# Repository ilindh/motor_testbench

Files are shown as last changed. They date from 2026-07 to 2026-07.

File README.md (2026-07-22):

<!-- KICAD_DIFF_GEN_START -->
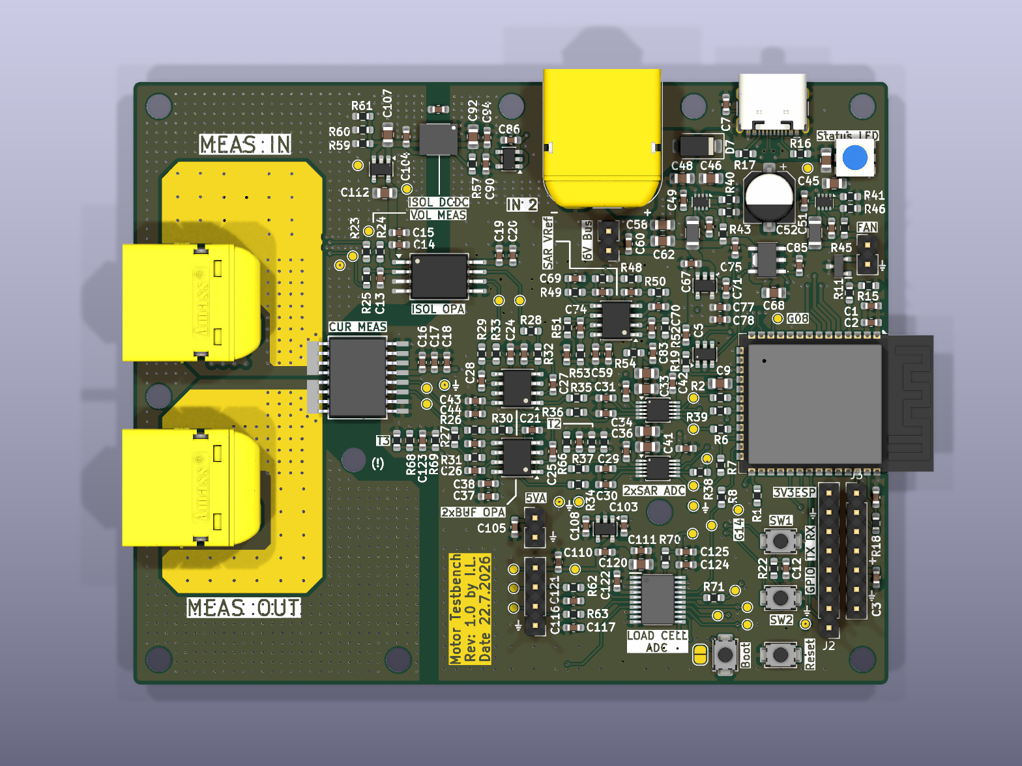
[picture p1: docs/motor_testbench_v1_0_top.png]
<p align="center"><br><b>Top</b></p>
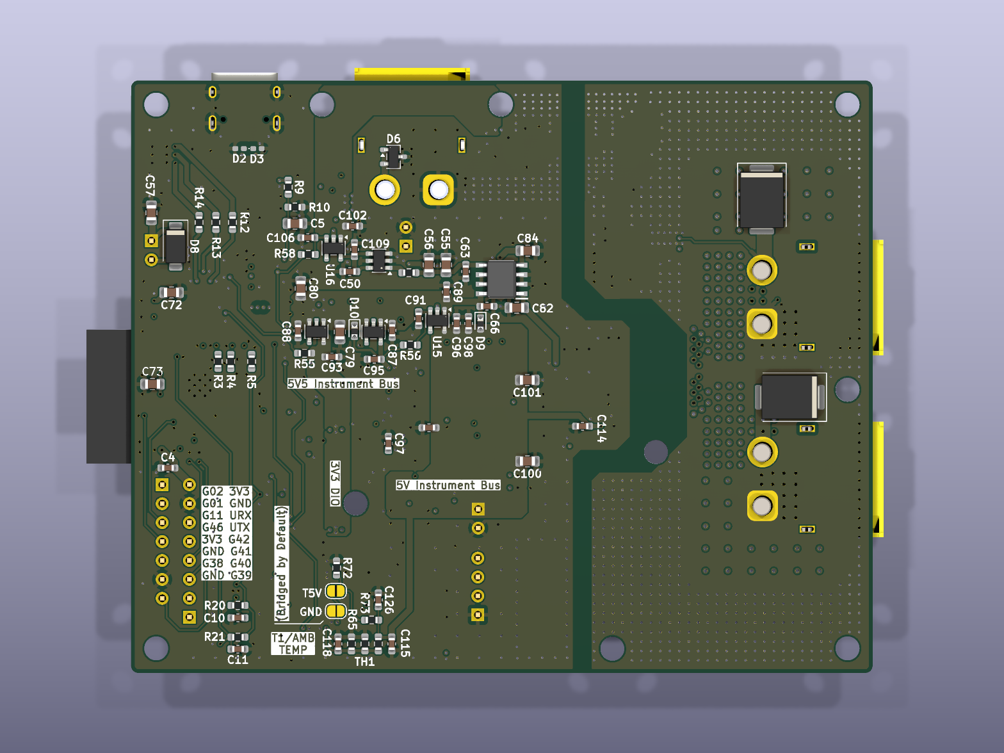
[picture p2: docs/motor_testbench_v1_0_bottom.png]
<p align="center"><br><b>Bottom</b></p>
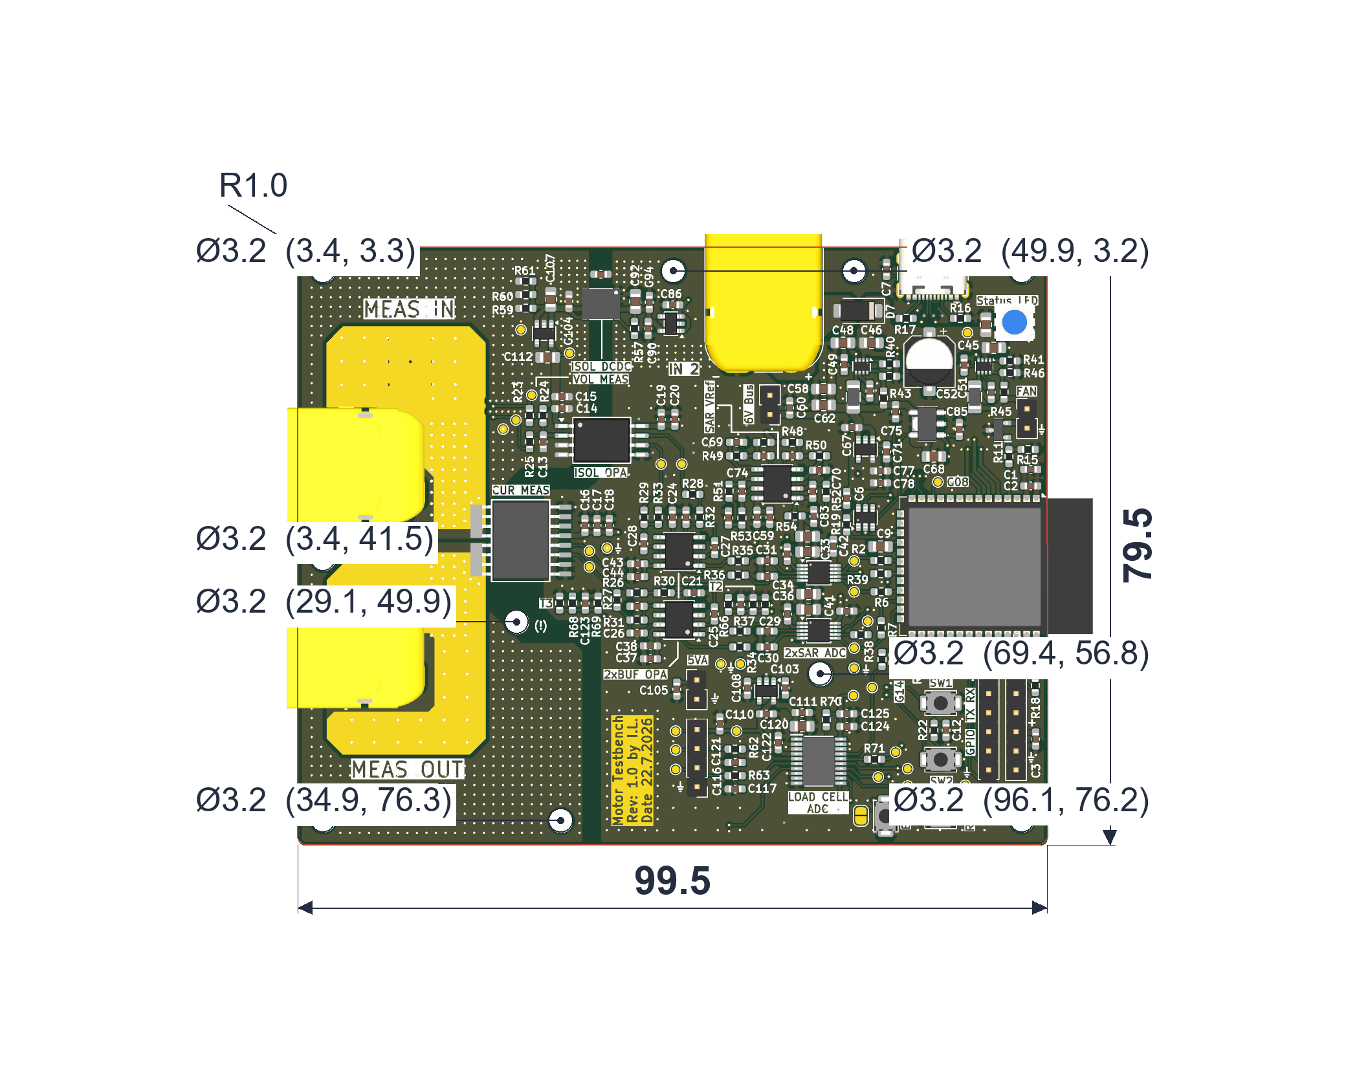
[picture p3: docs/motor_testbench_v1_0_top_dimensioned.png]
<p align="center"><br><b>Dimensions</b></p>

<p align="center"><br><b>Schematic — Page 1</b></p>
<p align="center"><br><b>Load Cell And Temperature Measurements — Page 2</b></p>
<p align="center"><br><b>Power Regulation — Page 3</b></p>
<p align="center"><br><b>Voltage And Current Measurements — Page 4</b></p>

---
## 🛠 Technical Hardware Summary
*Autogenerated by GitHub Command Center*

### 📋 Project Overview
| Metric | Value |
| :--- | :--- |
| **Board Dimensions** | 99.5 x 79.51 mm |
| **Total Area** | 7910.75 mm² |
| **Layer Count** | 6 Copper Layers |
| **Total Components** | 286 |
| **SMD Components** | 244 |
| **THT Components** | 9 |
| **Unique Parts** | 72 |
| **DRC Status** | ⚠️ 26 Errors, 106 Warnings |
| **KiCad Version** | 10.0.4 |

### 📐 Manufacturing & DRC
| Metric | Value |
| :--- | :--- |
| **Vias** | 1443 Total (1443 TH, 0 Blind, 0 Micro) |

### 📄 Architecture
- **Digital Buses:** `ESP_UART_RX, ESP_UART_TX, ESP_USB_D+, ESP_USB_D-`
- **Power Domains:** `+3V3, GND, GNDREF`

### ⚙️ Mechanical
- **Mounting Holes:** 10 (H10 (MountingHole_3.2mm_M3), H9 (MountingHole_3.2mm_M3), H7 (MountingHole_3.2mm_M3), H1 (MountingHole_3.2mm_M3), H8 (MountingHole_3.2mm_M3), H6 (MountingHole_3.2mm_M3), H2 (MountingHole_3.2mm_M3), H5 (MountingHole_3.2mm_M3), H4 (MountingHole_3.2mm_M3), H3 (MountingHole_3.2mm_M3))

### 🚫 Do Not Populate (DNP)
- C100 (22u)
- C101 (22u)
- C105 (1u)
- C126 (1u)
- C60 (1u)
- C8 (1u)
- C99 (100p)
- R18 (22R)
- R40 (R)
- R41 (R)
- R59 (220R)
- R60 (220R)
- R61 (220R)
- R72 (10k)
- R73 (10k)
- R8 (22R)

### 📝 Project TODOs
- TODO: Check Min / Max stable capacitances for the LDOS
- TODO: FIND PROPER 6V 800mA INPUT TO 3V3 LDO
- TODO: MAADOITA NÄMÄ?
- TODO: TARKASTA PINOUT: TLV9001SIDBVRG4\n
- TODO: VAIHDA TÄHÄN\nMouser No:\n637-PSOT36\nMfr. No:\nPSOT36
- TODO:\n\nVARMISTA ETTÄ PINNIT JA FOOTPRINT OIKEAT:\nPJA3402_R1_00001\nSOT-23-3\n

### 🧠 Core ICs & Modules
| Reference | Component | Function / Description |
| :--- | :--- | :--- |
| IC6 | [MCP3564RT-E_ST](https://componentsearchengine.com/search.html?searchString=MCP3564RT-E/ST) | Analog to Digital Converters - ADC 24-bit delta-sigma ADC w/Vref, Quad channel, 3V |
| IC1 | [PJA3402_R1_00001](https://componentsearchengine.com/search.html?searchString=PJA3402_R1_00001) | MOSFETs 30V N-Channel Enhancement Mode MOSFET |
| U1 | ESP32-S3-WROOM-1 | RF Module, ESP32-S3 SoC, Wi-Fi 802.11b/g/n, Bluetooth, BLE, 32-bit, 3.3V, onboard antenna, SMD |
| U2 | OPA310SxDBV | Single Rail-to-Rail Input/Output Operational Amplifier with Shutdown, 1.5..5.5V supply, 3MHz GBW, 250uV offset voltage, 150mA output current, SOT-23-6 |
| U8 | TPS62933 | 3.8-30V, 3A Synchronous Buck Converters with pulse frequency modulation (PFM), SOT583-8 |
| IC4 | [AP7361C-33Y5-13](https://componentsearchengine.com/search.html?searchString=AP7361C-33Y5-13) | DIODES INC. - AP7361C-33Y5-13 - LDO, FIXED, 3.3V, 1A, -40 TO 85DEG C |
| U10 | OPA2387DR | Precision, 10-MHz, Low-Noise, Low-Power, RRIO, CMOS Operational Amplifier, SOIC-8 |
| IC3 | [NCV8184DR2G](https://componentsearchengine.com/search.html?searchString=NCV8184DR2G) | 70 mA Source Capability; Output Tracks within +/- 3m V; Low Input Voltage Tracking Performance (Works Down to Vref = 2.0 V); Low Dropout (0.35 V Typ.@50 mA); Low Quiescent Current; Thermal Shutdown; AEC Qualified; PPAP Capable |
| U14 | TPS7A2018PDBVRG4 | LDO Voltage Regulators 300-mA ultra-low-noi se low-IQ low-dropo |
| U9 | TPS62933 | 3.8-30V, 3A Synchronous Buck Converters with pulse frequency modulation (PFM), SOT583-8 |
| U18 | TPS7A2045PDBVR | LDO Voltage Regulators 300-mA ultra-low-noi se low-IQ low-dropo |
| IC5 | [MIE1W0505BGLVH-3R-P](https://componentsearchengine.com/search.html?searchString=MIE1W0505BGLVH-3R-P) | Isolated DC/DC Converters - SMD Next gen ultra small size isolated power module |
| U7 | MCP1502T-50E/CHY | Voltage References 50 ppm 0.1% Voltage Reference |
| U11 | TPS7A2055PDBVR | LDO Voltage Regulators 300-mA ultra-low-noi se low-IQ low-dropo |
| U16 | TPS7A2055PDBVR | LDO Voltage Regulators 300-mA ultra-low-noi se low-IQ low-dropo |
| U15 | TPS7A2050PDBVR | LDO Voltage Regulators 300-mA ultra-low-noi se low-IQ low-dropo |
| U13 | TPS7A2033PDBVR | TPS7A2033PDBVR |
| U17 | TPS7A2033PDBVR | LDO Voltage Regulators 300-mA ultra-low-noi se low-IQ low-dropo |
| U12 | TPS7A2050PDBVR | LDO Voltage Regulators 300-mA ultra-low-noi se low-IQ low-dropo |
| U3 | [CZ3723](https://componentsearchengine.com/search.html?searchString=CZ3A05) | Board Mount Current Sensors 60A Precise unipolar Coreless Current Sensor w/UL61800 |
| U6 | OPA2328DR | Precision, 10-MHz, Low-Noise, Low-Power, RRIO, CMOS Operational Amplifier, SOIC-8 |
| U4 | AMC1351DWV | Precision Reinforced Isolated Amplifier, 5V Input, 300 kHz Bandwidth, 0.4V/V, 0.2% Gain Tolerance, Differential Output, SOIC-8 |
| U5 | OPA2328DR | Precision Amplifiers Dual-channel precis ion 50-uV offset vo |

### 🔌 Connectors & Interfaces
| Reference | Type | Component | Description |
| :--- | :--- | :--- | :--- |
| J11 | Connector | Conn_01x04_Pin | Generic connector, single row, 01x04, script generated |
| J3 | Connector | Conn_01x07_Pin | Generic connector, single row, 01x07, script generated |
| J1 | Connector | USB_C_Receptacle_USB2.0_16P | USB 2.0-only 16P Type-C Receptacle connector |
| J2 | Connector | Conn_01x08_Pin | Generic connector, single row, 01x08, script generated |
| J10 | Connector | Conn_01x02_Pin | Generic connector, single row, 01x02, script generated |
| J7 | Connector | Conn_01x02_Pin | Generic connector, single row, 01x02, script generated |
| J8 | Connector | Conn_01x02_Pin | Generic connector, single row, 01x02, script generated |
| J6 | Connector | V_bat_secondary | Generic connector, single row, 01x02, script generated |
| J5 | Connector | [XT60PW-M](https://componentsearchengine.com/search.html?searchString=XT60PW-M) | Connector: DC supply; socket; XT60; male; PIN: 2; on PCBs; THT; 30A |
| J4 | Connector | [XT60PW-M](https://componentsearchengine.com/search.html?searchString=XT60PW-M) | Connector: DC supply; socket; XT60; male; PIN: 2; on PCBs; THT; 30A |

### 📏 Passive Components
| Component | Breakdown |
| :--- | :--- |
| Capacitor | 97x0603, 28x0805 and 1xOther |
| Diode | 2x0402, 2x0603 and 6xOther |
| Inductor | 1x1206 |
| Resistor | 73x0603 |

---
<!-- KICAD_DIFF_GEN_END -->

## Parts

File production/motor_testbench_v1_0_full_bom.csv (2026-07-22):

Qty | Reference | Value | Footprint | Manufacturer_Part_Number | Description | DNP
63 | C1, C2, C3, C4, C6, C7, C14, C15, C16, C17, C18, C19, C20, C37, C38, C41, C42, C43, C44, C50, C59, C61, C63, C66, C67, C69, C70, C71, C77, C78, C81, C83, C85, C86, C87, C88, C89, C90, C91, C93, C94, C95, C96, C97, C98, C102, C103, C104, C106, C108, C109, C110, C111, C113, C114, C115, C118, C119, C121, C122, C123, C124, C125 | 1u | Capacitor_SMD:C_0603_1608Metric_Pad1.08x0.95mm_HandSolder |  | Unpolarized capacitor
16 | C5, C9, C45, C46, C47, C48, C55, C56, C68, C72, C73, C82, C84, C92, C112, C120 | 10u | Capacitor_SMD:C_0805_2012Metric_Pad1.18x1.45mm_HandSolder |  | Unpolarized capacitor
2 | C8, C126 | 1u | Capacitor_SMD:C_0603_1608Metric_Pad1.08x0.95mm_HandSolder |  | Unpolarized capacitor | DNP
2 | C10, C11 | 100n | Capacitor_SMD:C_0603_1608Metric_Pad1.08x0.95mm_HandSolder |  | BTN Debounce Cap
3 | C12, C53, C54 | 100n | Capacitor_SMD:C_0603_1608Metric_Pad1.08x0.95mm_HandSolder |  | Unpolarized capacitor
1 | C13 | 100p | Capacitor_SMD:C_0603_1608Metric_Pad1.08x0.95mm_HandSolder |  | USE 50V CAP HERE!, NP0 OR C0G SIGNAL CAP REQUIRED !
4 | C21, C22, C23, C24 | 100pF | Capacitor_SMD:C_0603_1608Metric_Pad1.08x0.95mm_HandSolder |  | SIGNAL CAP ! Use NP0 or similar.
4 | C25, C26, C27, C28 | 205pF | Capacitor_SMD:C_0603_1608Metric_Pad1.08x0.95mm_HandSolder |  | SIGNAL CAP ! Use NP0 or similar.
4 | C29, C30, C31, C32 | 1.7nF | Capacitor_SMD:C_0603_1608Metric_Pad1.08x0.95mm_HandSolder |  | SIGNAL CAP, USE NP0
4 | C33, C34, C35, C36 | 10u | Capacitor_SMD:C_0805_2012Metric_Pad1.18x1.45mm_HandSolder |  | SAR ADC Vref Capacitor (Very Cvritical!)
2 | C39, C40 | 1u | Capacitor_SMD:C_0603_1608Metric_Pad1.08x0.95mm_HandSolder |  | SAR ADC Ref Cap (critical)
2 | C49, C51 | 33n | Capacitor_SMD:C_0603_1608Metric_Pad1.08x0.95mm_HandSolder |  | Unpolarized capacitor
1 | C52 | 470u | Capacitor_SMD:CP_Elec_6.3x5.3 |  | Unpolarized capacitor
6 | C57, C58, C62, C79, C80, C107 | 22u | Capacitor_SMD:C_0805_2012Metric_Pad1.18x1.45mm_HandSolder |  | Unpolarized capacitor
2 | C64, C65 | 2.05u | Capacitor_SMD:C_0603_1608Metric_Pad1.08x0.95mm_HandSolder |  | Unpolarized capacitor
2 | C74, C76 | 4.7nF | Capacitor_SMD:C_0603_1608Metric_Pad1.08x0.95mm_HandSolder |  | Unpolarized capacitor
1 | C75 | 10u | Capacitor_SMD:C_0603_1608Metric_Pad1.08x0.95mm_HandSolder |  | Unpolarized capacitor
2 | C116, C117 | 100n | Capacitor_SMD:C_0603_1608Metric_Pad1.08x0.95mm_HandSolder |  | Load Cell Input Filter Capacitor, USE NP0
18 | CS1, CS2, DIO1, Dout1, GND1, GND2, GND3, GND4, GND5, I1, I2, I3, I4, IN1, SCLK1, Vref1, Vsig1, Vsig2 | TestPoint | TestPoint:TestPoint_Pad_D1.0mm |  | test point
1 | D1 | LED_RGB | LED_SMD:LED_RGB_PLCC-6 |  | RGB LED, 6 pin package
2 | D2, D3 | GG040205170N2P | Diode_SMD:D_0402_1005Metric_Pad0.77x0.64mm_HandSolder |  | Diode
2 | D4, D5 | 1.5SMCxxCA | Diode_SMD:D_SMC |  | 1500W bidirectional TVS diode, SMC (DO-201AB)
1 | D6 | ESDA5V3L | Package_TO_SOT_SMD:SOT-23-3 |  | TVS Diode Array, 5.5V Standoff, 2 Channels, SOT23
2 | D7, D8 | SB56AFC-AU_R1_000A1 | Diode_SMD:D_SMA |  | Schottky Diodes & Rectifiers 60V,Schottky,SMAF-C,5A
2 | D9, D10 | CDBU40-HF | Diode_SMD:D_0603_1608Metric |  | 40V 200mA Schottky Barrier Rectifier Diode, 0603
1 | IC1 | PJA3402_R1_00001 | SamacSys_Parts:SOT95P240X110-3N | PJA3402_R1_00001 | MOSFETs 30V N-Channel Enhancement Mode MOSFET
1 | IC3 | NCV8184DR2G | SamacSys_Parts:SOIC127P600X175-8N | NCV8184DR2G | 70 mA Source Capability; Output Tracks within +/- 3m V; Low Input Voltage Tracking Performance (Works Down to Vref = 2.0 V); Low Dropout (0.35 V Typ.@50 mA); Low Quiescent Current; Thermal Shutdown; AEC Qualified; PPAP Capable
1 | IC4 | AP7361C-33Y5-13 | SamacSys_Parts:AP7361CY513 | AP7361C-33Y5-13 | DIODES INC. - AP7361C-33Y5-13 - LDO, FIXED, 3.3V, 1A, -40 TO 85DEG C
1 | IC5 | MIE1W0505BGLVH-3R-P | SamacSys_Parts:MIE1W0505BGLVH3RP | MIE1W0505BGLVH-3R-P | Isolated DC/DC Converters - SMD Next gen ultra small size isolated power module
1 | IC6 | MCP3564RT-E_ST | SamacSys_Parts:SOP65P640X120-20N | MCP3564RT-E/ST | Analog to Digital Converters - ADC 24-bit delta-sigma ADC w/Vref, Quad channel, 3V
1 | J1 | USB_C_Receptacle_USB2.0_16P | Connector_USB:USB_C_Receptacle_HCTL_HC-TYPE-C-16P-01A |  | USB 2.0-only 16P Type-C Receptacle connector
1 | J2 | Conn_01x08_Pin | Connector_PinHeader_2.54mm:PinHeader_1x08_P2.54mm_Vertical |  | Generic connector, single row, 01x08, script generated
1 | J3 | Conn_01x07_Pin | Connector_PinHeader_2.54mm:PinHeader_1x07_P2.54mm_Vertical |  | Generic connector, single row, 01x07, script generated
2 | J4, J5 | XT60PW-M | Connector_AMASS:AMASS_XT60PW-M_1x02_P7.20mm_Horizontal | XT60PW-M | Connector: DC supply; socket; XT60; male; PIN: 2; on PCBs; THT; 30A
1 | J6 | V_bat_secondary | custom_footprints:AMASS_XT60PW-M_1x02_P7.20mm_Horizontal_with3DModel |  | Generic connector, single row, 01x02, script generated
3 | J7, J8, J10 | Conn_01x02_Pin | Connector_PinHeader_2.54mm:PinHeader_1x02_P2.54mm_Vertical |  | Generic connector, single row, 01x02, script generated
1 | J11 | Conn_01x04_Pin | Connector_PinHeader_2.54mm:PinHeader_1x04_P2.54mm_Vertical |  | Generic connector, single row, 01x04, script generated
1 | JP1 | Jumper_2_Open | Jumper:SolderJumper-2_P1.3mm_Open_RoundedPad1.0x1.5mm |  | Jumper, 2-pole, open
1 | L1 | 12u | Inductor_SMD:L_1206_3216Metric_Pad1.42x1.75mm_HandSolder |  | Inductor
1 | Lw1 | 6.8u | Inductor_SMD:L_1206_3216Metric_Pad1.42x1.75mm_HandSolder |  | Inductor
2 | MCP1, MCP2 | MCP33131D-10-E/MS | Package_SO:MSOP-10_3x3mm_P0.5mm |  | 16-bit ADC
1 | MCP33131 |  | Package_SO:MSOP-10_3x3mm_P0.5mm |  | 16-bit ADC
5 | R1, R10, R20, R21, R22 | 10k | Resistor_SMD:R_0603_1608Metric_Pad0.98x0.95mm_HandSolder |  | Voltage Meas Resistor 2
6 | R2, R6, R7, R19, R38, R39 | 22R | Resistor_SMD:R_0603_1608Metric_Pad0.98x0.95mm_HandSolder |  | Resistor
6 | R3, R4, R5, R62, R63, R71 | 22R | Resistor_SMD:R_0603_1608Metric_Pad0.98x0.95mm_HandSolder |  | Load Cell Inpu Filter Resistor
1 | R8 | 22R | Resistor_SMD:R_0603_1608Metric_Pad0.98x0.95mm_HandSolder |  | Load Cell Inpu Filter Resistor | DNP
1 | R9 | 100k | Resistor_SMD:R_0603_1608Metric_Pad0.98x0.95mm_HandSolder |  | Voltage Meas Resistor 1
1 | R11 | 220 | Resistor_SMD:R_0603_1608Metric_Pad0.98x0.95mm_HandSolder |  | Resistor
3 | R12, R13, R14 | 330R | Resistor_SMD:R_0603_1608Metric_Pad0.98x0.95mm_HandSolder
13 | R15, R44, R46, R49, R50, R51, R52, R55, R56, R58, R64, R66, R68 | 10k | Resistor_SMD:R_0603_1608Metric_Pad0.98x0.95mm_HandSolder |  | Resistor
2 | R16, R17 | 5.1k | Resistor_SMD:R_0603_1608Metric_Pad0.98x0.95mm_HandSolder |  | Resistor
1 | R18 | 22R | Resistor_SMD:R_0603_1608Metric_Pad0.98x0.95mm_HandSolder |  | Resistor | DNP
1 | R23 | 18k | Resistor_SMD:R_0603_1608Metric_Pad0.98x0.95mm_HandSolder |  | Voltage Meas Resistor 1
1 | R24 | 18k | Resistor_SMD:R_0603_1608Metric_Pad0.98x0.95mm_HandSolder |  | Voltage Meas Resistor 2
1 | R25 | 6.2k | Resistor_SMD:R_0603_1608Metric_Pad0.98x0.95mm_HandSolder |  | Voltage Meas Resistor 3 (RSENS)
4 | R26, R27, R28, R29 | 2.37k | Resistor_SMD:R_0603_1608Metric_Pad0.98x0.95mm_HandSolder |  | Sensitive Filter Resistor!
4 | R30, R31, R32, R33 | 3.32k | Resistor_SMD:R_0603_1608Metric_Pad0.98x0.95mm_HandSolder |  | Sensitive Filter Resistor!
4 | R34, R35, R36, R37 | 22R | Resistor_SMD:R_0603_1608Metric_Pad0.98x0.95mm_HandSolder |  | Sensitive Filter Resistor!
1 | R42 | 5R | Resistor_SMD:R_0603_1608Metric_Pad0.98x0.95mm_HandSolder |  | Resistor
1 | R43 | 63k | Resistor_SMD:R_0603_1608Metric_Pad0.98x0.95mm_HandSolder |  | Resistor
1 | R45 | 140k | Resistor_SMD:R_0603_1608Metric_Pad0.98x0.95mm_HandSolder |  | Resistor
2 | R47, R48 | 8.2k | Resistor_SMD:R_0603_1608Metric_Pad0.98x0.95mm_HandSolder |  | Resistor
2 | R53, R54 | 2R | Resistor_SMD:R_0603_1608Metric_Pad0.98x0.95mm_HandSolder |  | Resistor
1 | R57 | 100k | Resistor_SMD:R_0603_1608Metric_Pad0.98x0.95mm_HandSolder |  | Dummy Load Resistor for ISODCDC Converter, P = 0.25W
3 | R65, R67, R69 | 18k | Resistor_SMD:R_0603_1608Metric_Pad0.98x0.95mm_HandSolder |  | Resistor
1 | R70 | 100k | Resistor_SMD:R_0603_1608Metric_Pad0.98x0.95mm_HandSolder |  | Load Cell Inpu Filter Resistor
2 | R72, R73 | 10k | Resistor_SMD:R_0603_1608Metric_Pad0.98x0.95mm_HandSolder |  | NTC 5V Ref voltage divider resistors | DNP
4 | SWd1, SWd2, SWd3, SWd4 | SW_Push | Button_Switch_SMD:SW_SPST_TS-1088-xR020 |  | Push button switch, generic, two pins
3 | TH1, TH2, TH3 | NTCG164BH103JT1 | Resistor_SMD:R_0603_1608Metric_Pad0.98x0.95mm_HandSolder |  | Temperature dependent resistor, negative temperature coefficient
1 | U1 | ESP32-S3-WROOM-1 | RF_Module:ESP32-S3-WROOM-1 |  | RF Module, ESP32-S3 SoC, Wi-Fi 802.11b/g/n, Bluetooth, BLE, 32-bit, 3.3V, onboard antenna, SMD
1 | U2 | OPA310SxDBV | Package_TO_SOT_SMD:SOT-23-6 |  | Single Rail-to-Rail Input/Output Operational Amplifier with Shutdown, 1.5..5.5V supply, 3MHz GBW, 250uV offset voltage, 150mA output current, SOT-23-6
1 | U3 | CZ3723 | custom_footprints:CZ3723 | CZ3A05 | Board Mount Current Sensors 60A Precise unipolar Coreless Current Sensor w/UL61800
1 | U4 | AMC1351DWV | Package_SO:SOIC-8_7.5x5.85mm_P1.27mm |  | Precision Reinforced Isolated Amplifier, 5V Input, 300 kHz Bandwidth, 0.4V/V, 0.2% Gain Tolerance, Differential Output, SOIC-8
1 | U5 | OPA2328DR | Package_SO:SOIC-8_3.9x4.9mm_P1.27mm |  | Precision Amplifiers Dual-channel precis ion 50-uV offset vo
1 | U6 | OPA2328DR | Package_SO:SOIC-8_3.9x4.9mm_P1.27mm |  | Precision, 10-MHz, Low-Noise, Low-Power, RRIO, CMOS Operational Amplifier, SOIC-8
1 | U7 | MCP1502T-50E/CHY | Package_TO_SOT_SMD:SOT-23-6 |  | Voltage References 50 ppm 0.1% Voltage Reference
2 | U8, U9 | TPS62933 | Package_TO_SOT_SMD:SOT-583-8 |  | 3.8-30V, 3A Synchronous Buck Converters with pulse frequency modulation (PFM), SOT583-8
1 | U10 | OPA2387DR | Package_SO:SOIC-8_3.9x4.9mm_P1.27mm |  | Precision, 10-MHz, Low-Noise, Low-Power, RRIO, CMOS Operational Amplifier, SOIC-8
2 | U11, U16 | TPS7A2055PDBVR | Package_TO_SOT_SMD:SOT-23-5 |  | LDO Voltage Regulators 300-mA ultra-low-noi se low-IQ low-dropo
2 | U12, U15 | TPS7A2050PDBVR | Package_TO_SOT_SMD:SOT-23-5 |  | LDO Voltage Regulators 300-mA ultra-low-noi se low-IQ low-dropo
1 | U13 | TPS7A2033PDBVR | Package_TO_SOT_SMD:SOT-23-5 |  | TPS7A2033PDBVR
1 | U14 | TPS7A2018PDBVRG4 | Package_TO_SOT_SMD:SOT-23-5 |  | LDO Voltage Regulators 300-mA ultra-low-noi se low-IQ low-dropo
1 | U17 | TPS7A2033PDBVR | Package_TO_SOT_SMD:SOT-23-5 |  | LDO Voltage Regulators 300-mA ultra-low-noi se low-IQ low-dropo
1 | U18 | TPS7A2045PDBVR | Package_TO_SOT_SMD:SOT-23-5 |  | LDO Voltage Regulators 300-mA ultra-low-noi se low-IQ low-dropo

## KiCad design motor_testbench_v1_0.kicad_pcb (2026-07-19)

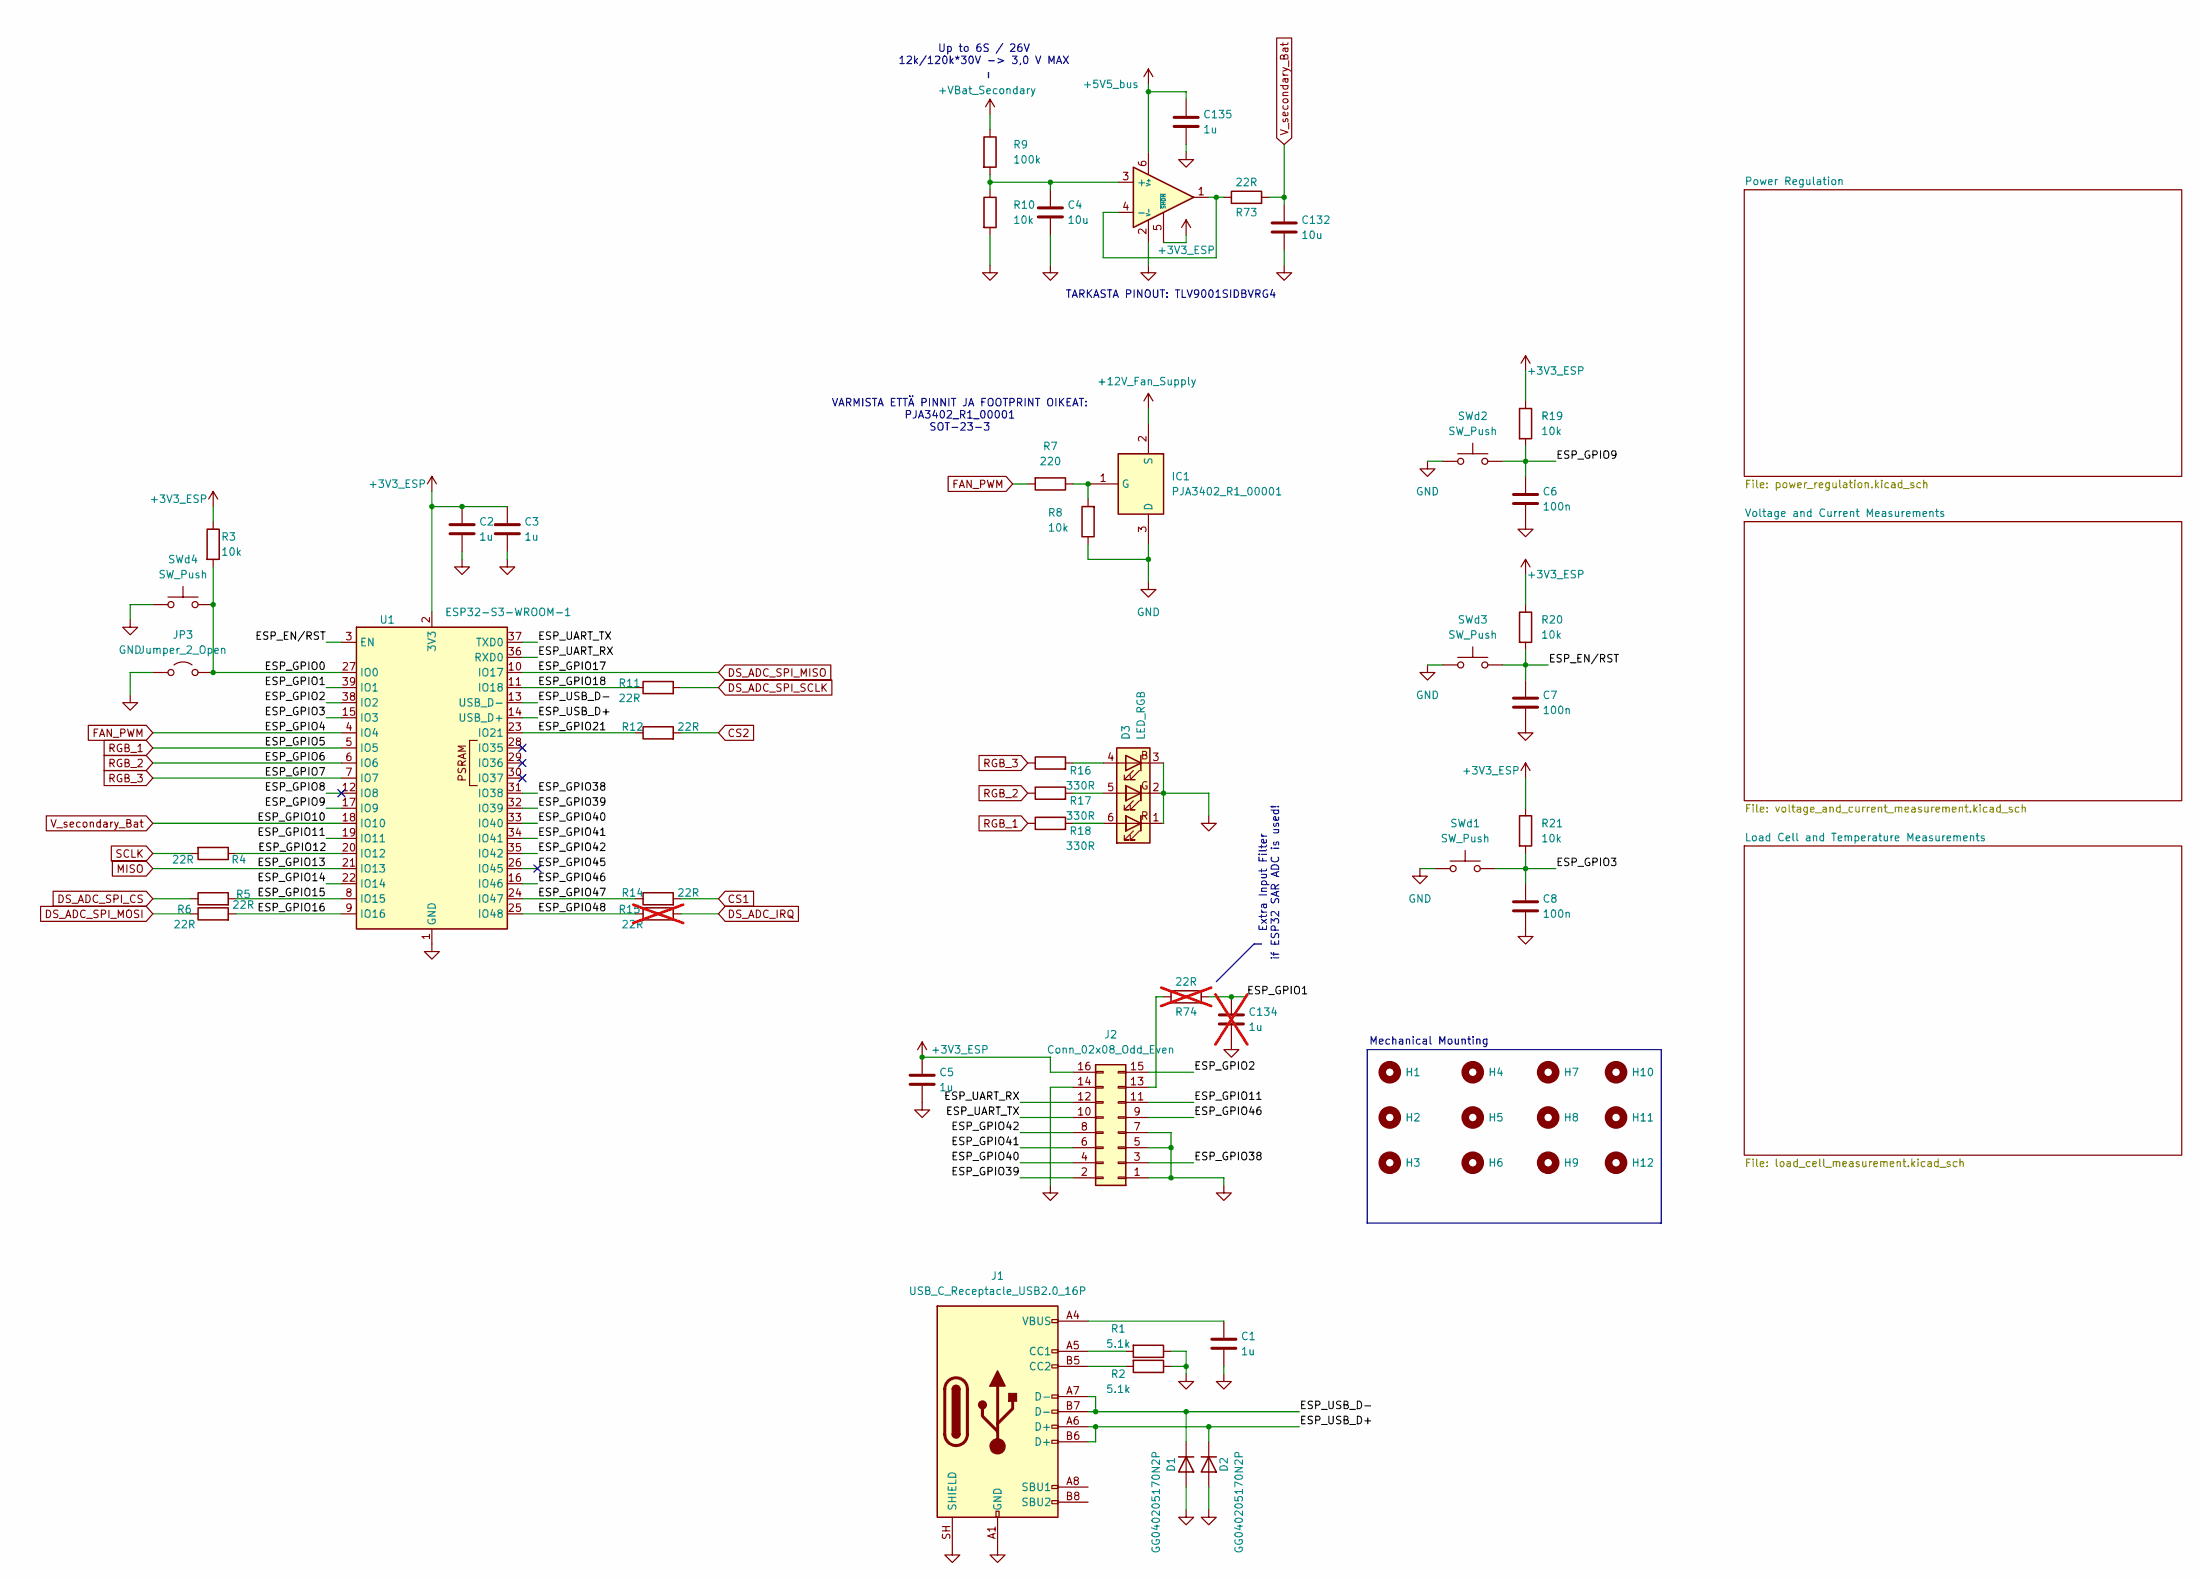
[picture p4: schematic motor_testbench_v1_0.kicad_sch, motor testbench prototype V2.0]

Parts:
C1, C2, C3, C5, C135: 1u; C_0603_1608Metric_Pad1.08x0.95mm_HandSolder
C4, C132: 10u; C_0603_1608Metric_Pad1.08x0.95mm_HandSolder
C6, C7, C8: 100n; C_0603_1608Metric_Pad1.08x0.95mm_HandSolder
C134: 1u; C_0603_1608Metric_Pad1.08x0.95mm_HandSolder; not fitted
D1, D2: GG040205170N2P; D_0402_1005Metric_Pad0.77x0.64mm_HandSolder
D3: LED_RGB; LED_RGB_PLCC-6
H1, H2, H3, H4, H5, H6, H7, H8, H9, H10, H11, H12: MountingHole; MountingHole_2.2mm_M2_DIN965
IC1: PJA3402_R1_00001; SOT95P240X110-3N; Manufacturer_Part_Number PJA3402_R1_00001
J1: USB_C_Receptacle_USB2.0_16P; USB_C_Receptacle_HCTL_HC-TYPE-C-16P-01A
J2: Conn_02x08_Odd_Even; PinHeader_2x08_P2.54mm_Vertical
JP3: Jumper_2_Open; SolderJumper-2_P1.3mm_Open_RoundedPad1.0x1.5mm
R1, R2: 5.1k; R_0603_1608Metric_Pad0.98x0.95mm_HandSolder
R3, R8, R10, R19, R20, R21: 10k; R_0603_1608Metric_Pad0.98x0.95mm_HandSolder
R4, R5, R6, R11, R12, R14, R73: 22R; R_0603_1608Metric_Pad0.98x0.95mm_HandSolder
R7: 220; R_0603_1608Metric_Pad0.98x0.95mm_HandSolder
R9: 100k; R_0603_1608Metric_Pad0.98x0.95mm_HandSolder
R15, R74: 22R; R_0603_1608Metric_Pad0.98x0.95mm_HandSolder; not fitted
R16, R17, R18: 330R; R_0603_1608Metric_Pad0.98x0.95mm_HandSolder
SWd1, SWd2, SWd3, SWd4: SW_Push; SW_SPST_TS-1088-xR020
U1: ESP32-S3-WROOM-1
U21: OPA310SxDBV; SOT-23-6

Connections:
+3V3_ESP: C2.1, C3.1, C5.1, J2.16, R3.1, R19.1, R20.1, R21.1, U1.2 (3V3), U21.5 (~SHDN); also elsewhere on the board
+5V5_bus: C135.1, U21.6 (V+); also elsewhere on the board
+12V_Fan_Supply: IC1.2 (S); also elsewhere on the board
+VBat_Secondary: R9.1; also elsewhere on the board
/ESP_EN/RST: C7.1, R20.2, SWd3.2, U1.3 (EN)
/ESP_GPIO0: JP3.2 (B), R3.2, SWd4.2, U1.27 (IO0)
/ESP_GPIO1: C134.1, R74.2, U1.39 (IO1)
/ESP_GPIO2: J2.15, U1.38 (IO2)
/ESP_GPIO3: C8.1, R21.2, SWd1.2, U1.15 (IO3)
/ESP_GPIO8: U1.12 (IO8)
/ESP_GPIO9: C6.1, R19.2, SWd2.2, U1.17 (IO9)
/ESP_GPIO11: J2.11, U1.19 (IO11)
/ESP_GPIO12: R4.1, U1.20 (IO12)
/ESP_GPIO14: U1.22 (IO14)
/ESP_GPIO15: R5.2, U1.8 (IO15)
/ESP_GPIO16: R6.2, U1.9 (IO16)
/ESP_GPIO18: R11.1, U1.11 (IO18)
/ESP_GPIO21: R12.1, U1.23 (IO21)
/ESP_GPIO38: J2.3, U1.31 (IO38)
/ESP_GPIO39: J2.2, U1.32 (IO39)
/ESP_GPIO40: J2.4, U1.33 (IO40)
/ESP_GPIO41: J2.6, U1.34 (IO41)
/ESP_GPIO42: J2.8, U1.35 (IO42)
/ESP_GPIO45: U1.26 (IO45)
/ESP_GPIO46: J2.9, U1.16 (IO46)
/ESP_GPIO47: R14.1, U1.24 (IO47)
/ESP_GPIO48: R15.1, U1.25 (IO48)
/ESP_UART_RX: J2.12, U1.36 (RXD0)
/ESP_UART_TX: J2.10, U1.37 (TXD0)
/ESP_USB_D+: D2.1 (K), J1.A6 (D+), J1.B6 (D+), U1.14 (USB_D+)
/ESP_USB_D-: D1.1 (K), J1.A7 (D-), J1.B7 (D-), U1.13 (USB_D-)
CS1: R14.2; also elsewhere on the board
CS2: R12.2; also elsewhere on the board
DS_ADC_IRQ: R15.2; also elsewhere on the board
DS_ADC_SPI_CS: R5.1; also elsewhere on the board
DS_ADC_SPI_MISO: U1.10 (IO17); also elsewhere on the board
DS_ADC_SPI_MOSI: R6.1; also elsewhere on the board
DS_ADC_SPI_SCLK: R11.2; also elsewhere on the board
FAN_PWM: R7.2, U1.4 (IO4)
GND: C1.2, C2.2, C3.2, C4.2, C5.2, C6.2, C7.2, C8.2, C132.2, C134.2, C135.2, D1.2 (A), D2.2 (A), D3.1 (RK), D3.2 (GK), D3.3 (BK), IC1.3 (D), J1.A1 (GND), J1.A12 (GND), J1.B1 (GND), J1.B12 (GND), J1.SH (SHIELD), J2.1, J2.5, J2.7, J2.14, JP3.1 (A), R1.1, R2.1, R8.1, R10.2, SWd1.1, SWd2.1, SWd3.1, SWd4.1, U1.1 (GND), U1.40 (GND), U1.41 (GND), U21.2 (V-); also elsewhere on the board
MISO: U1.21 (IO13); also elsewhere on the board
unnamed: C1.1, J1.A4 (VBUS), J1.A9 (VBUS), J1.B4 (VBUS), J1.B9 (VBUS)
unnamed: D3.4 (BA), R16.2
unnamed: D3.5 (GA), R17.2
unnamed: D3.6 (RA), R18.2
unnamed: IC1.1 (G), R7.1, R8.2
unnamed: J1.A5 (CC1), R1.2
unnamed: J1.B5 (CC2), R2.2
unnamed: J2.13, R74.1
unnamed: C4.1, R9.2, R10.1, U21.3 (+)
unnamed: R73.1, U21.1, U21.4 (-)
RGB_1: R18.1, U1.5 (IO5)
RGB_2: R17.1, U1.6 (IO6)
RGB_3: R16.1, U1.7 (IO7)
SCLK: R4.2; also elsewhere on the board
V_secondary_Bat: C132.1, R73.2, U1.18 (IO10)

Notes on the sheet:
Extra Input Filter if ESP32 SAR ADC is used!
Mechanical Mounting
TARKASTA PINOUT: TLV9001SIDBVRG4
VARMISTA ETTÄ PINNIT JA FOOTPRINT OIKEAT: PJA3402_R1_00001 SOT-23-3
Up to 6S / 26V 12k/120k*30V -> 3,0 V MAX

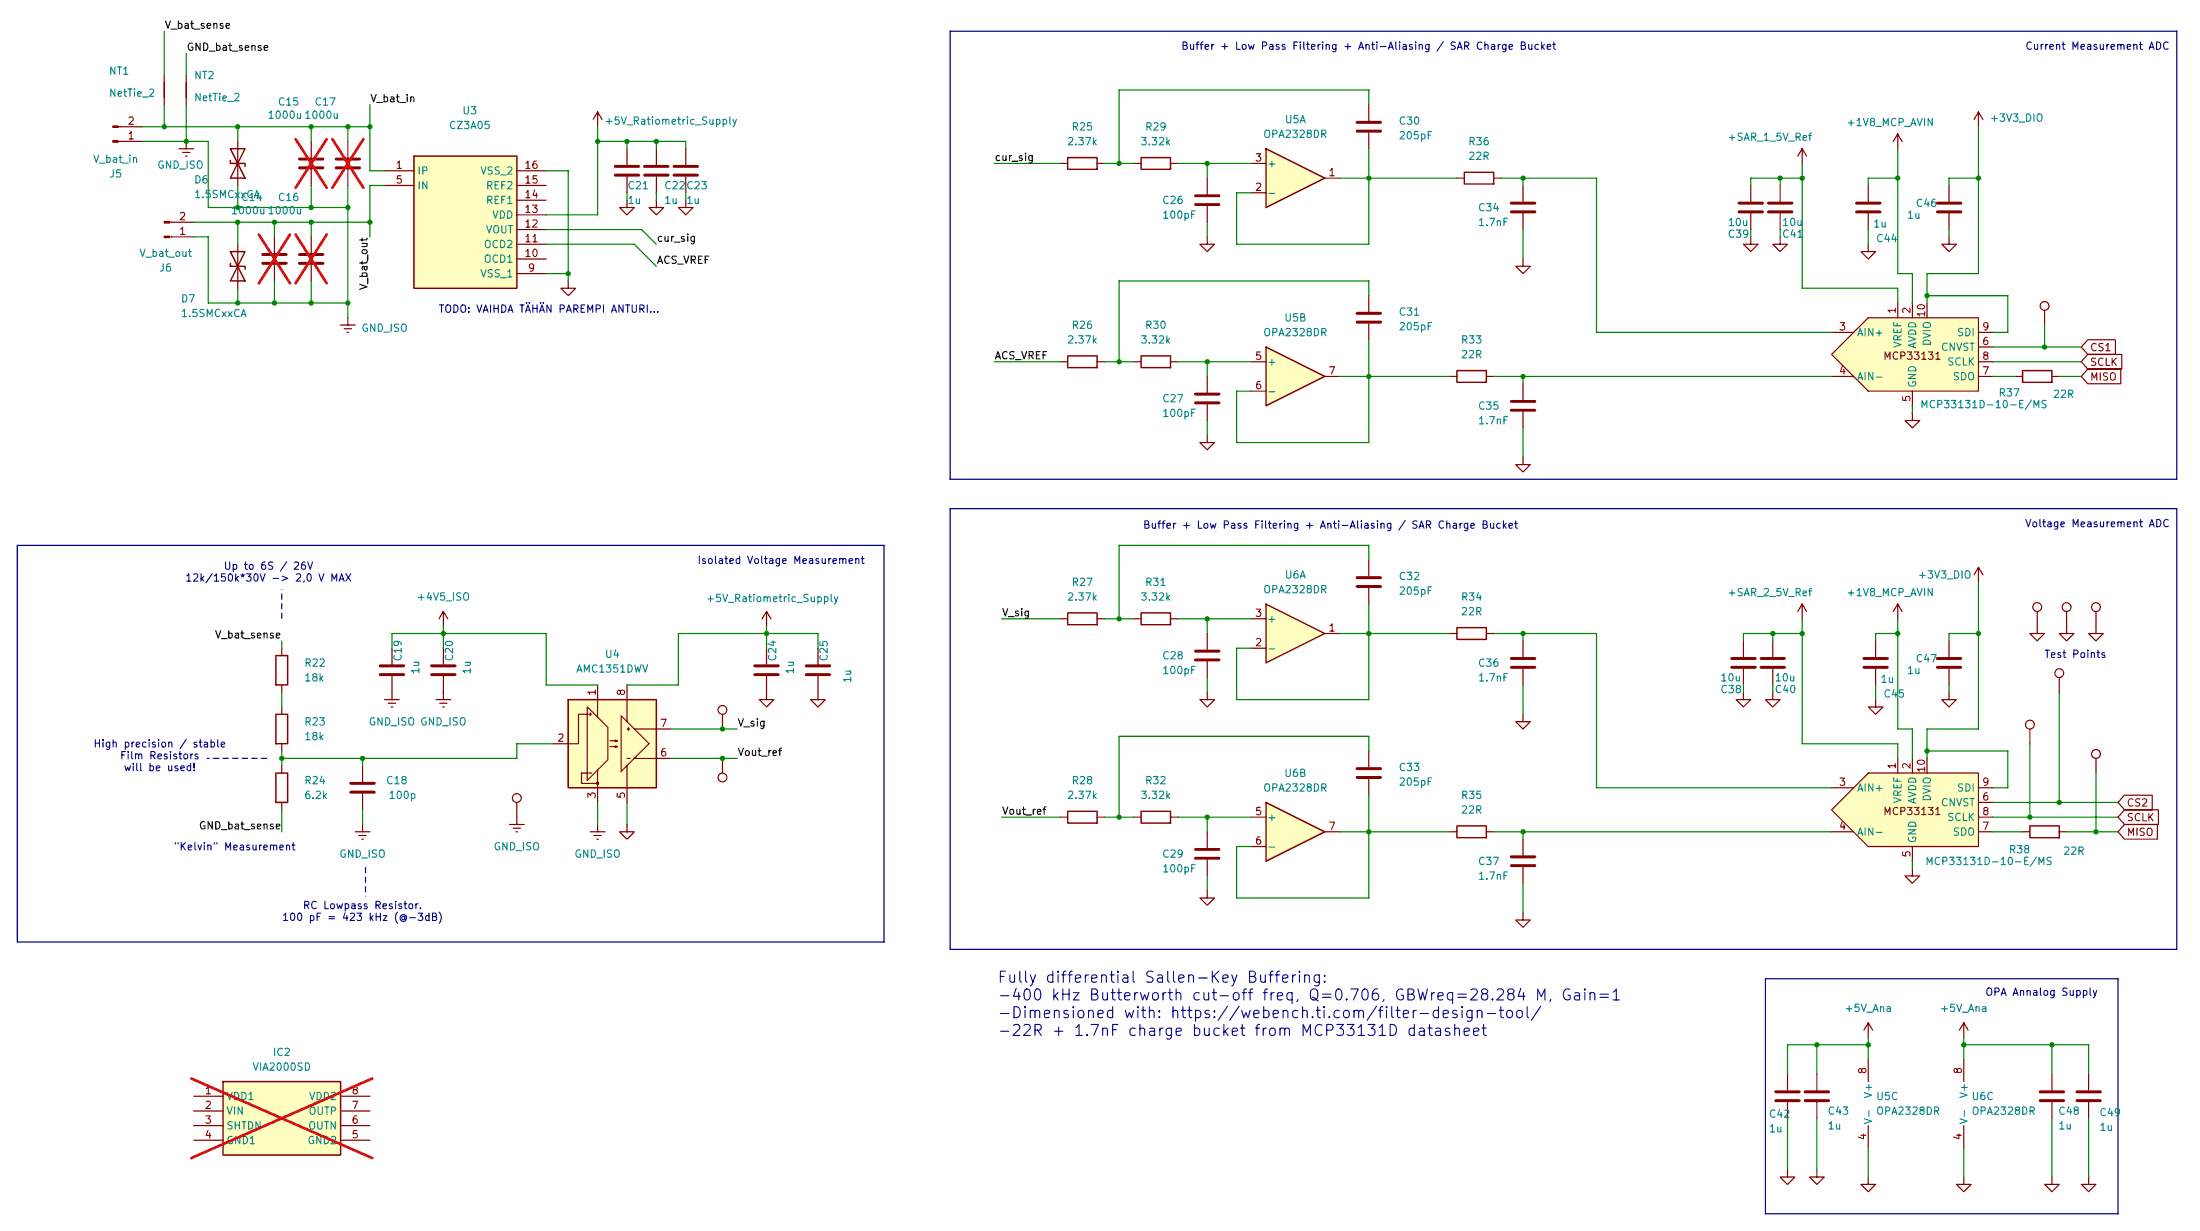
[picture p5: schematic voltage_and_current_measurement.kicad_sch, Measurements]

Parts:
C14, C15, C16, C17: 1000u; C_Radial_D8.0mm_H11.5mm_P3.50mm; not fitted
C18: 100p; C_0603_1608Metric_Pad1.08x0.95mm_HandSolder
C19, C20, C21, C22, C23, C24, C25, C42, C43, C44, C45, C46, C47, C48, C49: 1u; C_0603_1608Metric_Pad1.08x0.95mm_HandSolder
C26, C27, C28, C29: 100pF; C_0603_1608Metric_Pad1.08x0.95mm_HandSolder
C30, C31, C32, C33: 205pF; C_0603_1608Metric_Pad1.08x0.95mm_HandSolder
C34, C35, C36, C37: 1.7nF; C_0603_1608Metric_Pad1.08x0.95mm_HandSolder
C38, C39, C40, C41: 10u; C_0603_1608Metric_Pad1.08x0.95mm_HandSolder
CS1, CS2: TestPoint; TestPoint_Pad_D1.0mm
D6, D7: 1.5SMCxxCA; D_SMC
Dout1: TestPoint; TestPoint_Pad_D1.0mm
GND1, GND2, GND3, GND4: TestPoint; TestPoint_Pad_D1.0mm
IC2: VIA2000SD; SOIC127P1150X280-8N; Manufacturer_Part_Number VIA2000SD; not fitted
J5: V_bat_in; AMASS_XT60PW-M_1x02_P7.20mm_Horizontal_with3DModel
J6: V_bat_out; AMASS_XT60PW-M_1x02_P7.20mm_Horizontal_with3DModel
MCP1, MCP2: MCP33131D-10-E/MS; MSOP-10_3x3mm_P0.5mm
NT1, NT2: NetTie_2; NetTie-2_SMD_Pad0.5mm
R22, R23: 18k; R_0603_1608Metric_Pad0.98x0.95mm_HandSolder
R24: 6.2k; R_0603_1608Metric_Pad0.98x0.95mm_HandSolder
R25, R26, R27, R28: 2.37k; R_0603_1608Metric_Pad0.98x0.95mm_HandSolder
R29, R30, R31, R32: 3.32k; R_0603_1608Metric_Pad0.98x0.95mm_HandSolder
R33, R34, R35, R36, R37, R38: 22R; R_0603_1608Metric_Pad0.98x0.95mm_HandSolder
SCLK1: TestPoint; TestPoint_Pad_D1.0mm
U3: CZ3A05; Manufacturer_Part_Number CZ3A05; Mouser Part Number 412-CZ3A05
U4: AMC1351DWV; SOIC-8_7.5x5.85mm_P1.27mm
U5: OPA2328DR; SOIC-8_3.9x4.9mm_P1.27mm
U6: OPA2328DR; SOIC-8_3.9x4.9mm_P1.27mm; Mouser No: 595-OPA2328DR
Vsig1, Vsig2: TestPoint; TestPoint_Pad_D1.0mm

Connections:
+1V8_MCP_AVIN: C44.2, C45.2, MCP1.2 (AVDD), MCP2.2 (AVDD); also elsewhere on the board
+3V3_DIO: C46.1, C47.1, MCP1.9 (SDI), MCP1.10 (DVIO), MCP2.9 (SDI), MCP2.10 (DVIO); also elsewhere on the board
+4V5_ISO: C19.1, C20.1, U4.1 (VDD1); also elsewhere on the board
+5V_Ana: C42.1, C43.1, C48.1, C49.1, U5.8 (V+), U6.8 (V+); also elsewhere on the board
+5V_Ratiometric_Supply: C21.1, C22.1, C23.1, C24.1, C25.1, U3.13 (VDD), U4.8 (VDD2); also elsewhere on the board
+SAR_1_5V_Ref: C39.1, C41.1, MCP1.1 (VREF); also elsewhere on the board
+SAR_2_5V_Ref: C38.1, C40.1, MCP2.1 (VREF); also elsewhere on the board
/Voltage and Current Measurements/ACS_VREF: R26.1, U3.11 (OCD2); also elsewhere on the board
/Voltage and Current Measurements/GND_bat_sense: NT2.2, R24.2
/Voltage and Current Measurements/V_bat_in: C15.1, C17.1, D6.2 (A2), J5.2, NT1.1, U3.1 (IP)
/Voltage and Current Measurements/V_bat_out: C14.1, C16.1, D7.2 (A2), J6.2, U3.5 (IN)
/Voltage and Current Measurements/V_bat_sense: NT1.2, R22.1
/Voltage and Current Measurements/V_sig: R27.1, U4.7 (OUTP), Vsig1.1 (1_1)
/Voltage and Current Measurements/Vout_ref: R28.1, U4.6 (OUTN), Vsig2.1 (1_1)
/Voltage and Current Measurements/cur_sig: R25.1, U3.12 (VOUT); also elsewhere on the board
CS1: CS1.1 (1_1), MCP1.6 (CNVST); also elsewhere on the board
CS2: CS2.1 (1_1), MCP2.6 (CNVST); also elsewhere on the board
GND: C21.2, C22.2, C23.2, C24.2, C25.2, C26.2, C27.2, C28.2, C29.2, C34.2, C35.2, C36.2, C37.2, C38.2, C39.2, C40.2, C41.2, C42.2, C43.2, C44.1, C45.1, C46.2, C47.2, C48.2, C49.2, GND2.1 (1_1), GND3.1 (1_1), GND4.1 (1_1), MCP1.5 (GND), MCP2.5 (GND), U3.9 (VSS_1), U3.16 (VSS_2), U4.5 (GND2), U5.4 (V-), U6.4 (V-); also elsewhere on the board
GND_ISO: C14.2, C15.2, C16.2, C17.2, C18.2, C19.2, C20.2, D6.1 (A1), D7.1 (A1), GND1.1 (1_1), J5.1, J6.1, NT2.1, U4.3 (GND1), U4.4 (GND1); also elsewhere on the board
MISO: Dout1.1 (1_1), R37.2, R38.2; also elsewhere on the board
unnamed: C30.1, R25.2, R29.1
unnamed: C31.1, R26.2, R30.1
unnamed: C32.1, R27.2, R31.1
unnamed: C33.1, R28.2, R32.1
unnamed: C34.1, MCP1.3 (AIN+), R36.2
unnamed: C35.1, MCP1.4 (AIN-), R33.2
unnamed: MCP1.7 (SDO), R37.1
unnamed: C36.1, MCP2.3 (AIN+), R34.2
unnamed: C37.1, MCP2.4 (AIN-), R35.2
unnamed: MCP2.7 (SDO), R38.1
unnamed: R22.2, R23.1
unnamed: C18.1, R23.2, R24.1, U4.2 (IN)
unnamed: C26.1, R29.2, U5.3 (+)
unnamed: C30.2, R36.1, U5.1, U5.2 (-)
unnamed: C27.1, R30.2, U5.5 (+)
unnamed: C31.2, R33.1, U5.6 (-), U5.7
unnamed: C28.1, R31.2, U6.3 (+)
unnamed: C32.2, R34.1, U6.1, U6.2 (-)
unnamed: C29.1, R32.2, U6.5 (+)
unnamed: C33.2, R35.1, U6.6 (-), U6.7
SCLK: MCP1.8 (SCLK), MCP2.8 (SCLK), SCLK1.1 (1_1); also elsewhere on the board

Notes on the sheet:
RC Lowpass Resistor. 100 pF = 423 kHz (@-3dB)
TODO: VAIHDA TÄHÄN PAREMPI ANTURI...
Up to 6S / 26V 12k/150k*30V -> 2,0 V MAX
OPA Annalog Supply
Voltage Measurement ADC
Buffer + Low Pass Filtering + Anti-Aliasing / SAR Charge Bucket
Isolated Voltage Measurement
Current Measurement ADC
Test Points
High precision / stable Film Resistors will be used!
Fully differential Sallen-Key Buffering: -400 kHz Butterworth cut-off freq, Q=0.706, GBWreq=28.284 M, Gain=1 -Dimensioned with: https://webench.ti.com/filter-design-tool/ -22R + 1.7nF charge bucket from MCP33131D datasheet
"Kelvin" Measurement

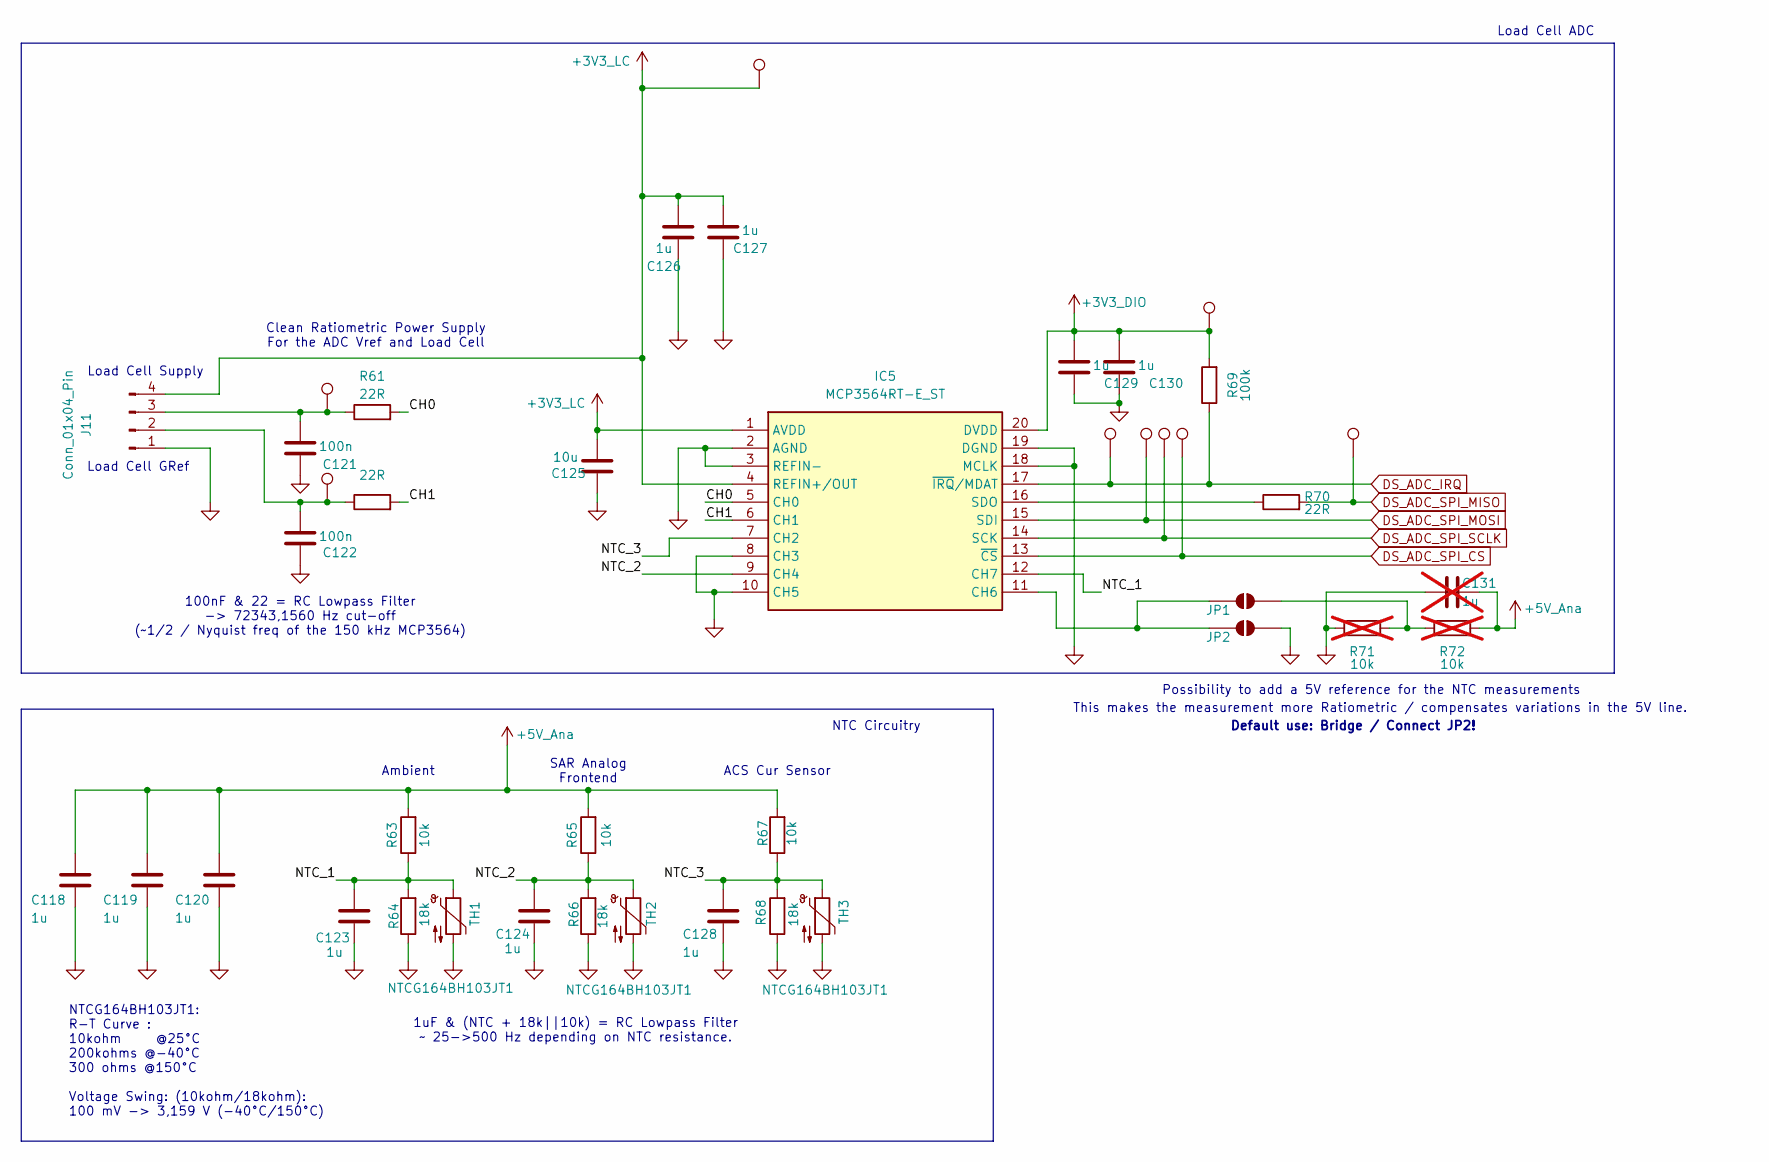
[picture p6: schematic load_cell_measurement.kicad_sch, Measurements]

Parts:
C118, C119, C120, C123, C124, C126, C127, C128, C129, C130: 1u; C_0603_1608Metric_Pad1.08x0.95mm_HandSolder
C121, C122: 100n; C_0603_1608Metric_Pad1.08x0.95mm_HandSolder
C125: 10u; C_0603_1608Metric_Pad1.08x0.95mm_HandSolder
C131: 1u; C_0603_1608Metric_Pad1.08x0.95mm_HandSolder; not fitted
I1, I2, I3, I5, I6, I7, I8, I9, I10: TestPoint; TestPoint_Pad_D1.0mm
IC5: MCP3564RT-E_ST; SOP65P640X120-20N; Manufacturer_Part_Number MCP3564RT-E/ST; Mouser Part Number 579-MCP3564RT-E/ST
J11: Conn_01x04_Pin; PinHeader_1x04_P2.54mm_Vertical
JP1, JP2: SolderJumper_2_Open; SolderJumper-2_P1.3mm_Open_RoundedPad1.0x1.5mm
R61, R62, R70: 22R; R_0603_1608Metric_Pad0.98x0.95mm_HandSolder
R63, R65, R67: 10k; R_0603_1608Metric_Pad0.98x0.95mm_HandSolder
R64, R66, R68: 18k; R_0603_1608Metric_Pad0.98x0.95mm_HandSolder
R69: 100k; R_0603_1608Metric_Pad0.98x0.95mm_HandSolder
R71, R72: 10k; R_0603_1608Metric_Pad0.98x0.95mm_HandSolder; not fitted
TH1, TH2, TH3: NTCG164BH103JT1; R_0603_1608Metric_Pad0.98x0.95mm_HandSolder

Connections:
+3V3_DIO: C129.2, C130.2, I9.1 (1_1), IC5.20 (DVDD), R69.2; also elsewhere on the board
+3V3_LC: C125.2, C126.2, C127.2, I3.1 (1_1), IC5.1 (AVDD), IC5.4 (REFIN+/OUT), J11.4; also elsewhere on the board
+5V_Ana: C118.1, C119.1, C120.1, C131.2, R63.2, R65.2, R67.2, R72.2; also elsewhere on the board
/Load Cell and Temperature Measurements/CH0: IC5.5 (CH0), R61.2
/Load Cell and Temperature Measurements/CH1: IC5.6 (CH1), R62.2
/Load Cell and Temperature Measurements/NTC_1: C123.1, IC5.12 (CH7), R63.1, R64.2, TH1.1
/Load Cell and Temperature Measurements/NTC_2: C124.1, IC5.9 (CH4), R65.1, R66.2, TH2.1
/Load Cell and Temperature Measurements/NTC_3: C128.1, IC5.7 (CH2), R67.1, R68.2, TH3.1
DS_ADC_IRQ: I5.1 (1_1), IC5.17 (~IRQ/MDAT), R69.1; also elsewhere on the board
DS_ADC_SPI_CS: I8.1 (1_1), IC5.13 (~CS); also elsewhere on the board
DS_ADC_SPI_MISO: I10.1 (1_1), R70.2; also elsewhere on the board
DS_ADC_SPI_MOSI: I6.1 (1_1), IC5.15 (SDI); also elsewhere on the board
DS_ADC_SPI_SCLK: I7.1 (1_1), IC5.14 (SCK); also elsewhere on the board
GND: C118.2, C119.2, C120.2, C121.1, C122.1, C123.2, C124.2, C125.1, C126.1, C127.1, C128.2, C129.1, C130.1, C131.1, IC5.2 (AGND), IC5.3 (REFIN-), IC5.8 (CH3), IC5.10 (CH5), IC5.18 (MCLK), IC5.19 (DGND), J11.1, JP2.2 (B), R64.1, R66.1, R68.1, R71.1, TH1.2, TH2.2, TH3.2; also elsewhere on the board
unnamed: IC5.11 (CH6), JP1.1 (A), JP2.1 (A)
unnamed: IC5.16 (SDO), R70.1
unnamed: C122.2, I2.1 (1_1), J11.2, R62.1
unnamed: C121.2, I1.1 (1_1), J11.3, R61.1
unnamed: JP1.2 (B), R71.2, R72.1

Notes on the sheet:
100nF & 22 = RC Lowpass Filter -> 72343,1560 Hz cut-off (~1/2 / Nyquist freq of the 150 kHz MCP3564)
SAR Analog Frontend
Default use: Bridge / Connect JP2!
NTC Circuitry
NTCG164BH103JT1: R-T Curve : 10kohm @25°C 200kohms @-40°C 300 ohms @150°C Voltage Swing: (10kohm/18kohm): 100 mV -> 3,159 V (-40°C/150°C)
ACS Cur Sensor
Clean Ratiometric Power Supply For the ADC Vref and Load Cell
This makes the measurement more Ratiometric / compensates variations in the 5V line.
Load Cell GRef
Load Cell ADC
Ambient
Possibility to add a 5V reference for the NTC measurements
1uF & (NTC + 18k||10k) = RC Lowpass Filter ~ 25->500 Hz depending on NTC resistance.
Load Cell Supply

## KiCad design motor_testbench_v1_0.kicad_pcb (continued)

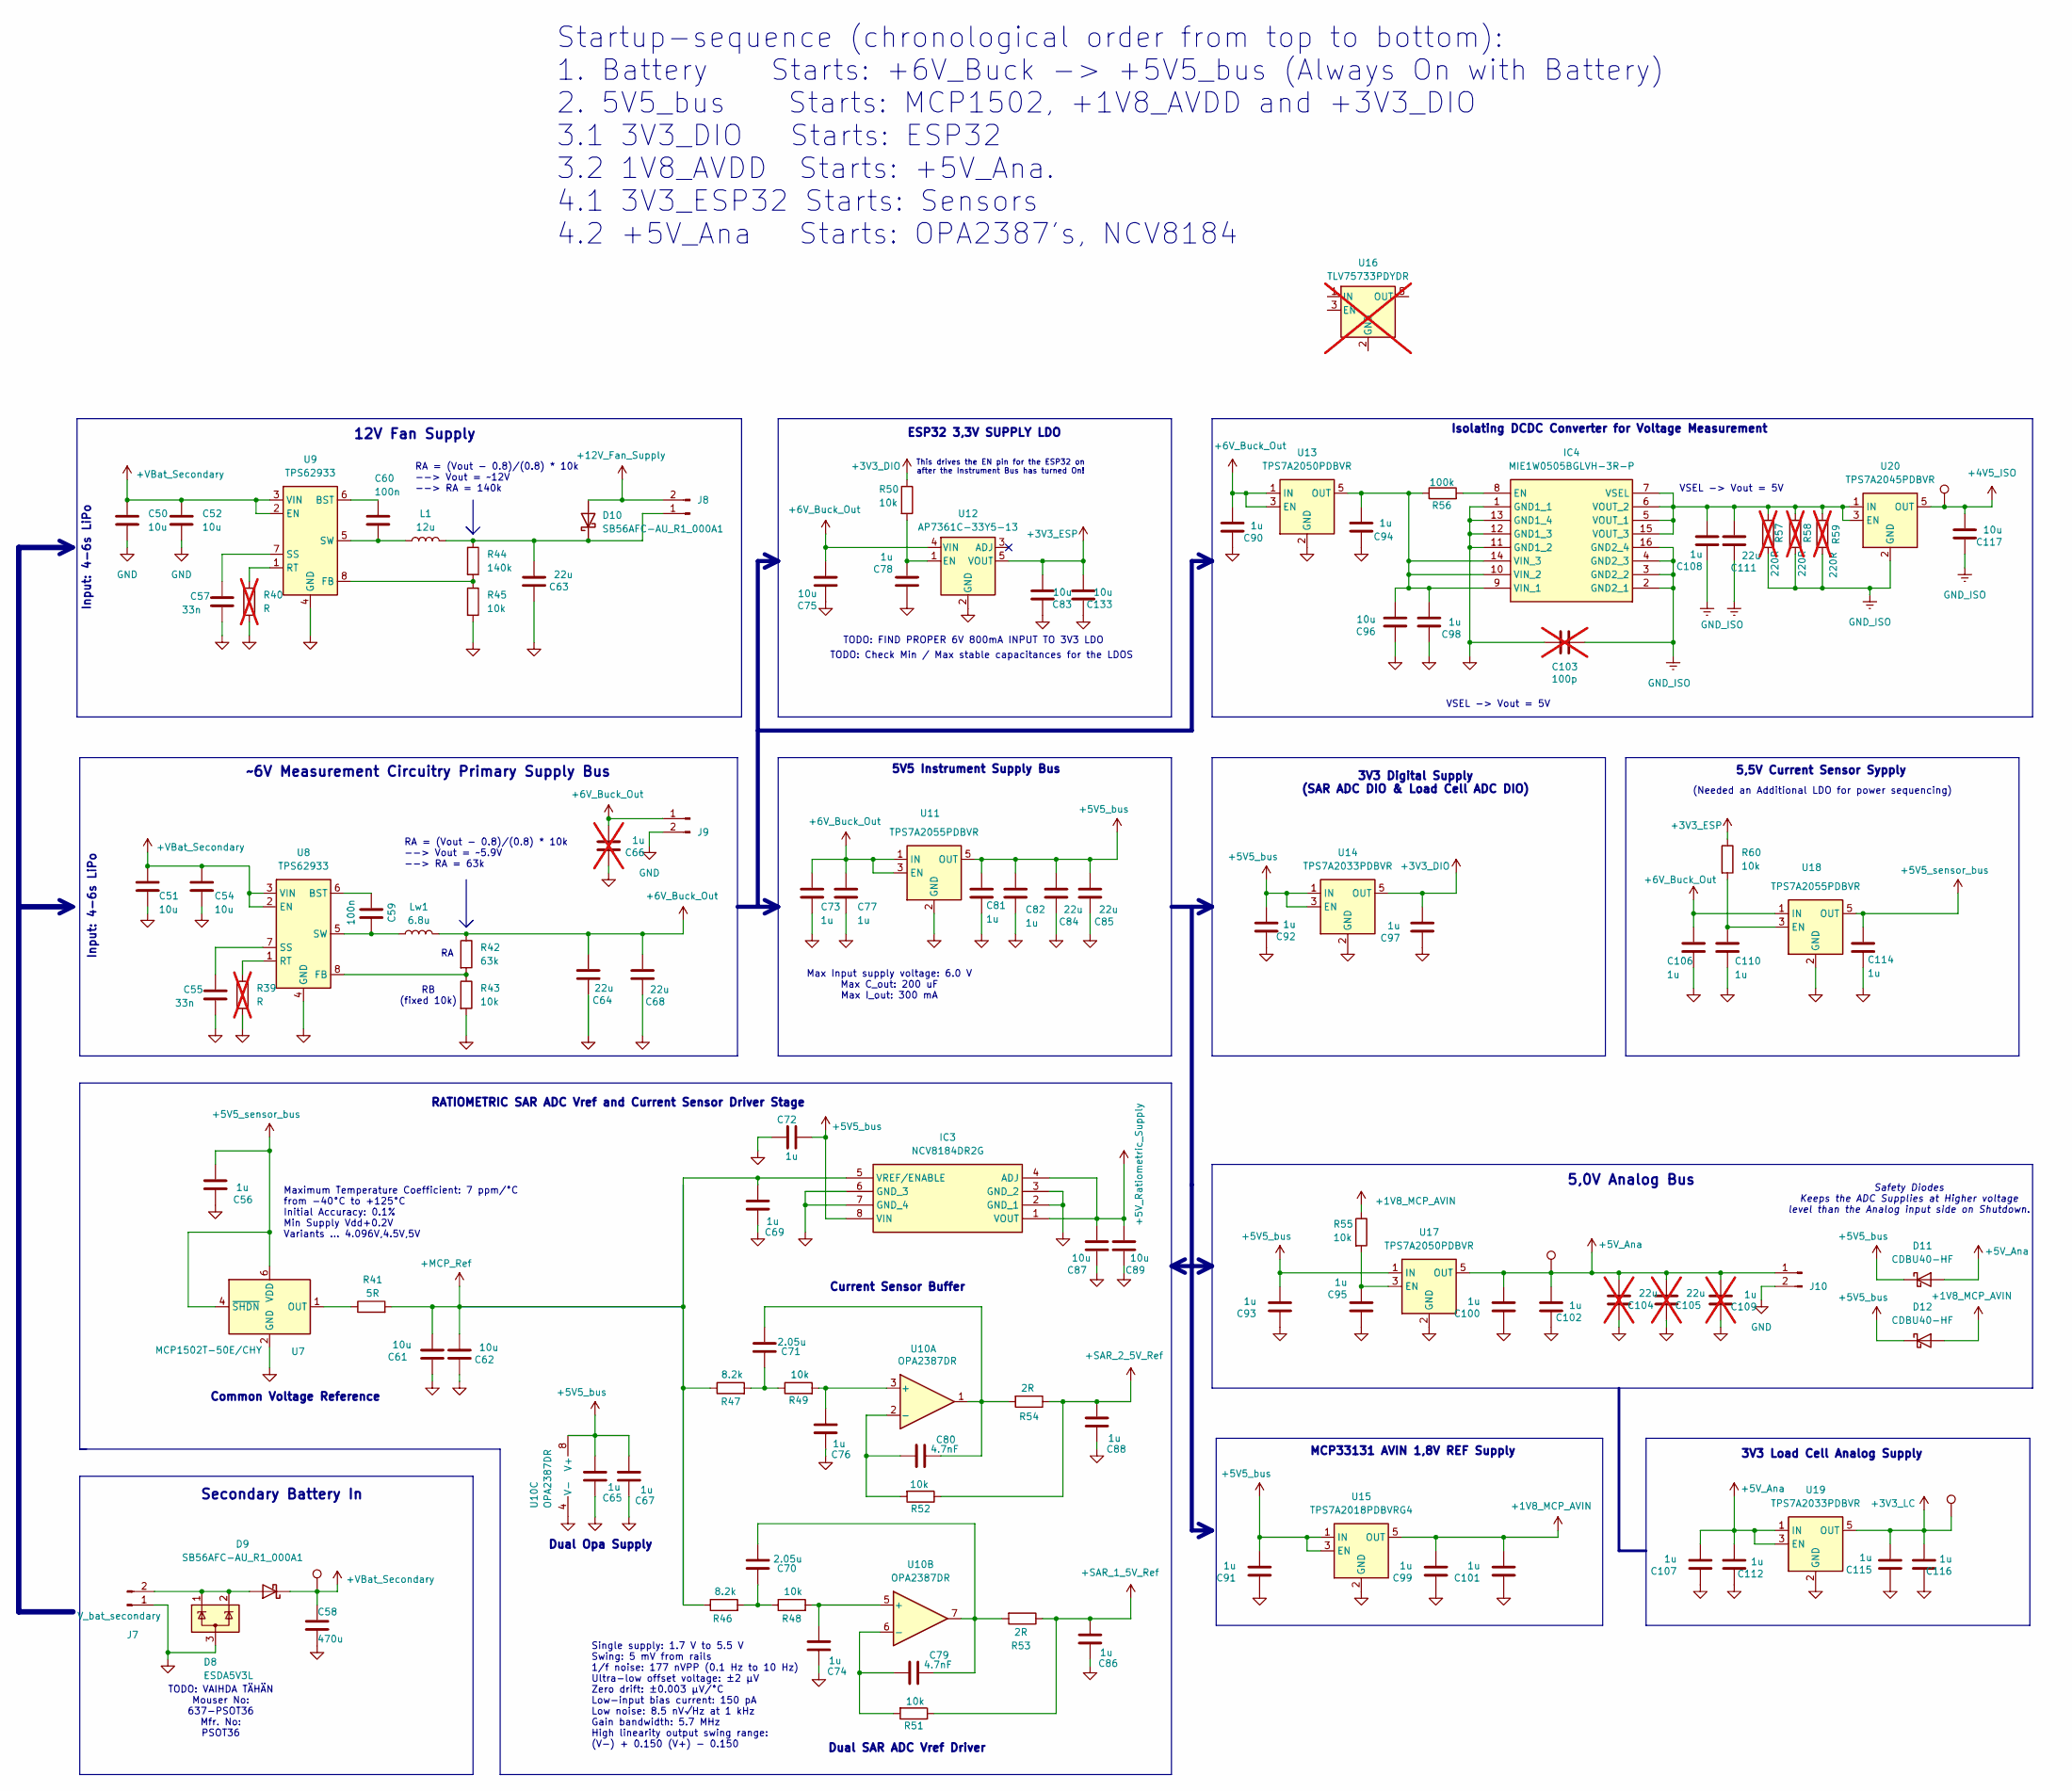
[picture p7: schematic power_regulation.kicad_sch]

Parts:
C50, C51, C52, C54, C61, C62, C75, C83, C87, C89, C96, C117, C133: 10u; C_0603_1608Metric_Pad1.08x0.95mm_HandSolder
C55, C57: 33n; C_0603_1608Metric_Pad1.08x0.95mm_HandSolder
C56, C65, C67, C69, C72, C73, C74, C76, C77, C78, C81, C82, C86, C88, C90, C91, C92, C93, C94, C95, C97, C98, C99, C100, C101, C102, C106, C107, C108, C110, C112, C114, C115, C116: 1u; C_0603_1608Metric_Pad1.08x0.95mm_HandSolder
C58: 470u; CP_Elec_6.3x5.3
C59, C60: 100n; C_0603_1608Metric_Pad1.08x0.95mm_HandSolder
C63, C64, C68, C84, C85, C111: 22u; C_1206_3216Metric_Pad1.33x1.80mm_HandSolder
C66, C109: 1u; C_0603_1608Metric_Pad1.08x0.95mm_HandSolder; not fitted
C70, C71: 2.05u; C_0603_1608Metric_Pad1.08x0.95mm_HandSolder
C79, C80: 4.7nF; C_0603_1608Metric_Pad1.08x0.95mm_HandSolder
C103: 100p; C_0603_1608Metric_Pad1.08x0.95mm_HandSolder; not fitted
C104, C105: 22u; C_1206_3216Metric_Pad1.33x1.80mm_HandSolder; not fitted
D8: ESDA5V3L; SOT-23-3
D9, D10: SB56AFC-AU_R1_000A1; D_SMA
D11, D12: CDBU40-HF; D_0603_1608Metric
DIO1: TestPoint; TestPoint_Pad_D1.0mm
IC3: NCV8184DR2G; SOIC127P600X175-8N; Manufacturer_Part_Number NCV8184DR2G; Mouser Part Number 863-NCV8184DR2G
IC4: MIE1W0505BGLVH-3R-P; MIE1W0505BGLVH3RP; Manufacturer_Part_Number MIE1W0505BGLVH-3R-P; Mouser Part Number 946-MIE1W0505BGLVH3P
IN1: TestPoint; TestPoint_Pad_D1.0mm
J7: V_bat_secondary; AMASS_XT60PW-M_1x02_P7.20mm_Horizontal_with3DModel
J8, J9, J10: Conn_01x02_Pin; PinHeader_1x02_P2.54mm_Vertical
L1: 12u; L_1206_3216Metric_Pad1.42x1.75mm_HandSolder
Lw1: 6.8u; L_1206_3216Metric_Pad1.42x1.75mm_HandSolder
R39, R40: R; R_0603_1608Metric_Pad0.98x0.95mm_HandSolder; not fitted
R41: 5R; R_0603_1608Metric_Pad0.98x0.95mm_HandSolder
R42: 63k; R_0603_1608Metric_Pad0.98x0.95mm_HandSolder
R43, R45, R48, R49, R50, R51, R52, R55, R60: 10k; R_0603_1608Metric_Pad0.98x0.95mm_HandSolder
R44: 140k; R_0603_1608Metric_Pad0.98x0.95mm_HandSolder
R46, R47: 8.2k; R_0603_1608Metric_Pad0.98x0.95mm_HandSolder
R53, R54: 2R; R_0603_1608Metric_Pad0.98x0.95mm_HandSolder
R56: 100k; R_0603_1608Metric_Pad0.98x0.95mm_HandSolder
R57, R58, R59: 220R; R_0603_1608Metric_Pad0.98x0.95mm_HandSolder; not fitted
U7: MCP1502T-50E/CHY; SOT-23-6
U8, U9: TPS62933; SOT-583-8
U10: OPA2387DR; SOIC-8_3.9x4.9mm_P1.27mm
U11, U18: TPS7A2055PDBVR; SOT-23-5; Mouser_nro 595-TPS7A2055PDBVR
U12: AP7361C-33Y5-13; SOT-89-5_Handsoldering
U13, U17: TPS7A2050PDBVR; SOT-23-5
U14, U19: TPS7A2033PDBVR; SOT-23-5
U15: TPS7A2018PDBVRG4; SOT-23-5
U16: TLV75733PDYDR; SOT-23-5; not fitted
U20: TPS7A2045PDBVR; SOT-23-5
Vref1, Vref2: TestPoint; TestPoint_Pad_D1.0mm

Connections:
+1V8_MCP_AVIN: C99.2, C101.2, D12.2 (A), R55.1, U15.5 (OUT); also elsewhere on the board
+3V3_DIO: C97.2, R50.1, U14.5 (OUT); also elsewhere on the board
+3V3_ESP: C83.2, C133.2, R60.1, U12.5 (VOUT); also elsewhere on the board
+3V3_LC: C115.2, C116.2, DIO1.1 (1_1), U19.5 (OUT); also elsewhere on the board
+4V5_ISO: C117.2, U20.5 (OUT), Vref2.1 (1_1); also elsewhere on the board
+5V5_bus: C65.2, C67.2, C72.2, C81.1, C82.1, C84.2, C85.2, C91.2, C92.2, C93.2, D11.1 (K), D12.1 (K), IC3.8 (VIN), U10.8 (V+), U11.5 (OUT), U14.1 (IN), U14.3 (EN), U15.1 (IN), U15.3 (EN), U17.1 (IN); also elsewhere on the board
+5V5_sensor_bus: C56.2, C114.1, U7.4 (~SHDN), U7.6 (VDD), U18.5 (OUT)
+5V_Ana: C100.2, C102.2, C104.2, C105.2, C107.2, C109.2, C112.2, D11.2 (A), J10.1, U17.5 (OUT), U19.1 (IN), U19.3 (EN), Vref1.1 (1_1); also elsewhere on the board
+5V_Ratiometric_Supply: C87.2, C89.2, IC3.1 (VOUT), IC3.4 (ADJ); also elsewhere on the board
+6V_Buck_Out: C64.2, C66.2, C68.2, C73.1, C75.2, C77.1, C90.2, C106.1, J9.1, Lw1.2, R42.1, U11.1 (IN), U11.3 (EN), U12.4 (VIN), U13.1 (IN), U13.3 (EN), U18.1 (IN)
+12V_Fan_Supply: D10.2 (A), J8.2; also elsewhere on the board
+MCP_Ref: C61.2, C62.2, C69.2, IC3.5 (VREF/ENABLE), R41.2, R46.1, R47.1
+SAR_1_5V_Ref: C86.2, R51.1, R53.1; also elsewhere on the board
+SAR_2_5V_Ref: C88.2, R52.1, R54.1; also elsewhere on the board
+VBat_Secondary: C50.1, C51.1, C52.1, C54.1, C58.1, D9.1 (K), IN1.1 (1_1), U8.2 (EN), U8.3 (VIN), U9.2 (EN), U9.3 (VIN); also elsewhere on the board
GND: C50.2, C51.2, C52.2, C54.2, C55.2, C56.1, C57.2, C58.2, C61.1, C62.1, C63.1, C64.1, C65.1, C66.1, C67.1, C68.1, C69.1, C72.1, C73.2, C74.1, C75.1, C76.1, C77.2, C78.1, C81.2, C82.2, C83.1, C84.1, C85.1, C86.1, C87.1, C88.1, C89.1, C90.1, C91.1, C92.1, C93.1, C94.1, C95.1, C96.1, C97.1, C98.1, C99.1, C100.1, C101.1, C102.1, C103.2, C104.1, C105.1, C106.2, C107.1, C109.1, C110.2, C112.1, C114.2, C115.1, C116.1, C133.1, D8.3 (A), IC3.2 (GND_1), IC3.3 (GND_2), IC3.6 (GND_3), IC3.7 (GND_4), IC4.1 (GND1_1), IC4.11 (GND1_2), IC4.12 (GND1_3), IC4.13 (GND1_4), J7.1, J9.2, J10.2, R39.2, R40.2, R43.2, R45.2, U7.2 (GND), U7.3 (GND), U7.5 (GND), U8.4 (GND), U9.4 (GND), U10.4 (V-), U11.2 (GND), U12.2 (GND), U13.2 (GND), U14.2 (GND), U15.2 (GND), U17.2 (GND), U18.2 (GND), U19.2 (GND); also elsewhere on the board
GND_ISO: C103.1, C108.1, C111.1, C117.1, IC4.2 (GND2_1), IC4.3 (GND2_2), IC4.4 (GND2_3), IC4.16 (GND2_4), R57.2, R58.2, R59.2, U20.2 (GND); also elsewhere on the board
unnamed: C70.1, R46.2, R48.1
unnamed: C70.2, C79.2, R53.2, U10.7
unnamed: C71.1, R47.2, R49.1
unnamed: C71.2, C80.2, R54.2, U10.1
unnamed: D8.1 (K), D8.2 (K), D9.2 (A), J7.2
unnamed: C63.2, D10.1 (K), J8.1, L1.2, R44.1
unnamed: IC4.8 (EN), R56.2
unnamed: C94.2, C96.2, C98.2, IC4.9 (VIN_1), IC4.10 (VIN_2), IC4.14 (VIN_3), R56.1, U13.5 (OUT)
unnamed: C108.2, C111.2, IC4.5 (VOUT_1), IC4.6 (VOUT_2), IC4.7 (VSEL), IC4.15 (VOUT_3), R57.1, R58.1, R59.1, U20.1 (IN), U20.3 (EN)
unnamed: R41.1, U7.1 (OUT)
unnamed: C59.1, U8.6 (BST)
unnamed: R42.2, R43.1, U8.8 (FB)
unnamed: R39.1, U8.1 (RT)
unnamed: C55.1, U8.7 (SS)
unnamed: C59.2, Lw1.1, U8.5 (SW)
unnamed: C60.1, U9.6 (BST)
unnamed: R44.2, R45.1, U9.8 (FB)
unnamed: R40.1, U9.1 (RT)
unnamed: C57.1, U9.7 (SS)
unnamed: C60.2, L1.1, U9.5 (SW)
unnamed: C76.2, R49.2, U10.3 (+)
unnamed: C80.1, R52.2, U10.2 (-)
unnamed: C74.2, R48.2, U10.5 (+)
unnamed: C79.1, R51.2, U10.6 (-)
unnamed: C78.2, R50.2, U12.1 (EN)
unnamed: C95.2, R55.2, U17.3 (EN)
unnamed: C110.1, R60.2, U18.3 (EN)

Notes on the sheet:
Safety Diodes Keeps the ADC Supplies at Higher voltage level than the Analog input side on Shutdown.
Dual Opa Supply
ESP32 3,3V SUPPLY LDO
Max Input supply voltage: 6.0 V Max C_out: 200 uF Max I_out: 300 mA
TODO: VAIHDA TÄHÄN Mouser No: 637-PSOT36 Mfr. No: PSOT36
(Needed an Additional LDO for power sequencing)
This drives the EN pin for the ESP32 on after the Instrument Bus has turned On!
TODO: Check Min / Max stable capacitances for the LDOS
RATIOMETRIC SAR ADC Vref and Current Sensor Driver Stage
RA = (Vout - 0.8)/(0.8) * 10k --> Vout = ~12V --> RA = 140k
MCP33131 AVIN 1,8V REF Supply
Input: 4-6s LiPo
Startup-sequence (chronological order from top to bottom): 1. Battery Starts: +6V_Buck -> +5V5_bus (Always On with Battery) 2. 5V5_bus Starts: MCP1502, +1V8_AVDD and +3V3_DIO 3.1 3V3_DIO Starts: ESP32 3.2 1V8_AVDD Starts: +5V_Ana. 4.1 3V3_ESP32 Starts: Sensors 4.2 +5V_Ana Starts: OPA2387's, NCV8184
5,5V Current Sensor Sypply
12V Fan Supply
Dual SAR ADC Vref Driver
RA = (Vout - 0.8)/(0.8) * 10k --> Vout = ~5.9V --> RA = 63k
Single supply: 1.7 V to 5.5 V Swing: 5 mV from rails 1/f noise: 177 nVPP (0.1 Hz to 10 Hz) Ultra-low offset voltage: ±2 µV Zero drift: ±0.003 µV/°C Low-input bias current: 150 pA Low noise: 8.5 nV√Hz at 1 kHz Gain bandwidth: 5.7 MHz High linearity output swing range: (V-) + 0.150 (V+) - 0.150
Current Sensor Buffer
RB (fixed 10k)
5,0V Analog Bus
VSEL -> Vout = 5V
5V5 Instrument Supply Bus
Common Voltage Reference
Secondary Battery In
Maximum Temperature Coefficient: 7 ppm/°C from -40°C to +125°C Initial Accuracy: 0.1% Min Supply Vdd+0.2V Variants ... 4.096V,4.5V,5V
3V3 Digital Supply (SAR ADC DIO & Load Cell ADC DIO)
Isolating DCDC Converter for Voltage Measurement
TODO: FIND PROPER 6V 800mA INPUT TO 3V3 LDO
~6V Measurement Circuitry Primary Supply Bus
3V3 Load Cell Analog Supply

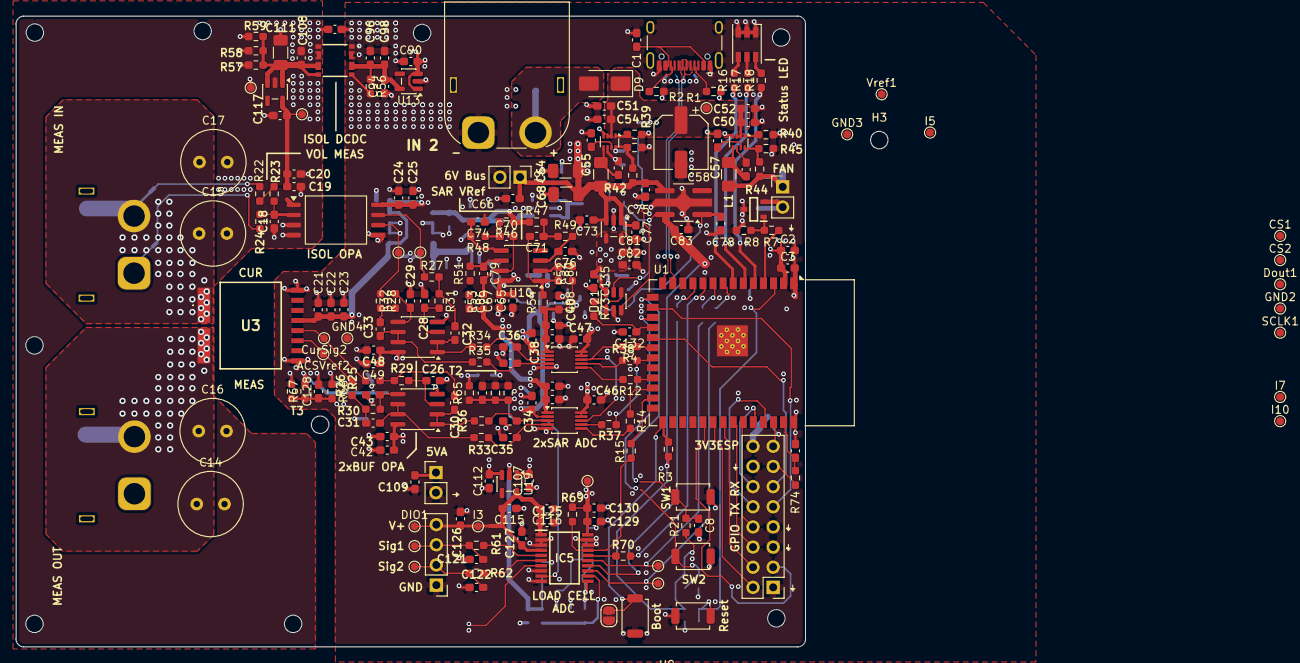
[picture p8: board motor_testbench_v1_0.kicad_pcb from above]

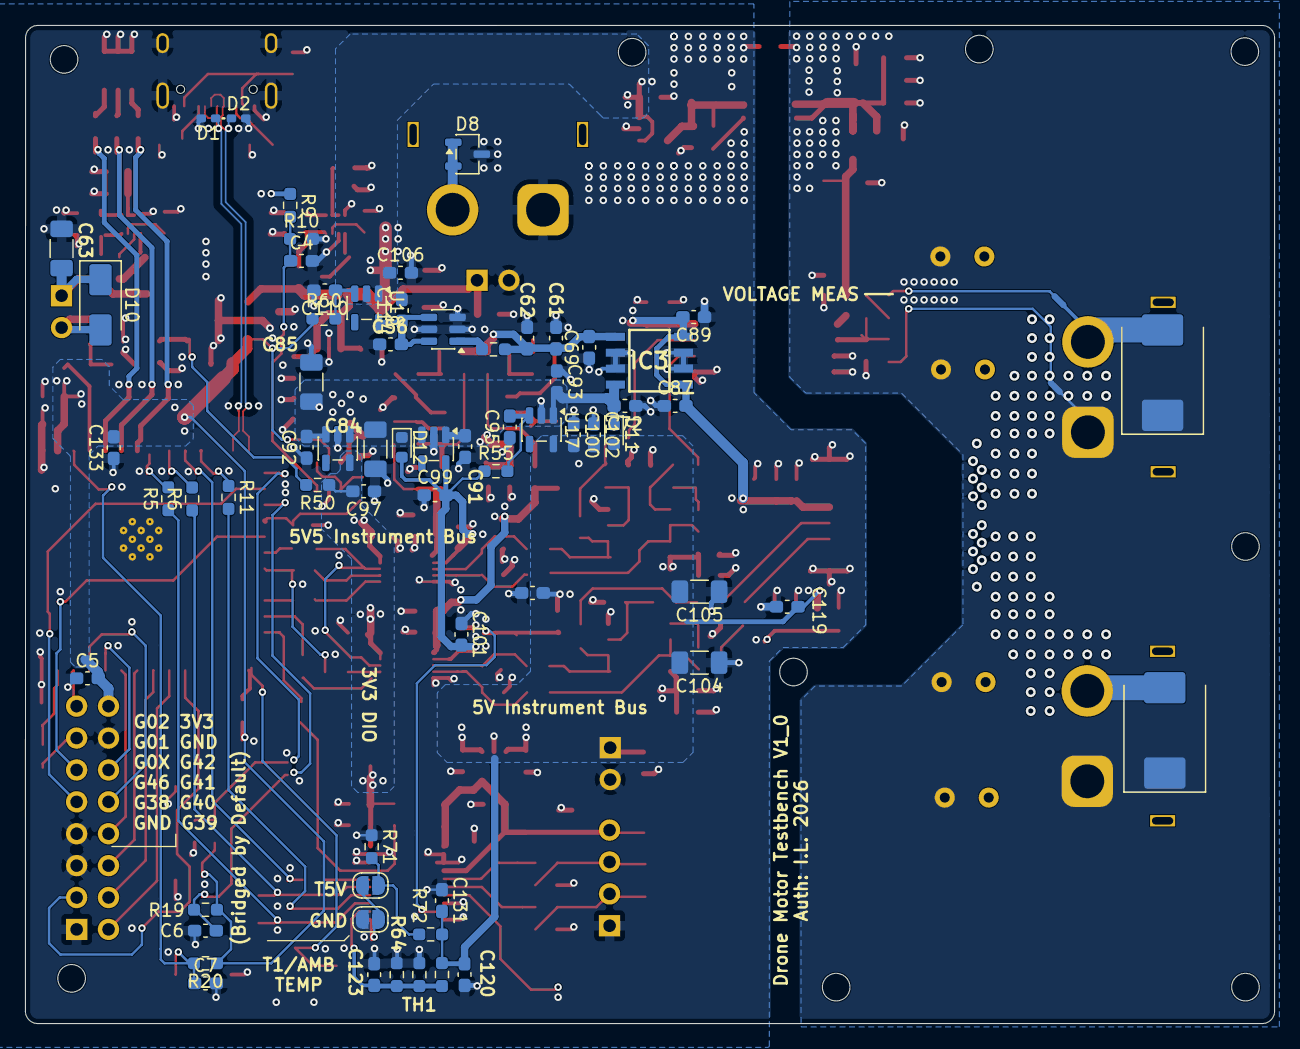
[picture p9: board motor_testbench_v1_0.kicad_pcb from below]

Board: 4 copper layers, 99.5 x 79.5 mm, 296 parts (68 on the bottom side), 130 nets.

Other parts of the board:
ACSVref2: TestPoint; TestPoint_Pad_D1.0mm
CurSig2: TestPoint; TestPoint_Pad_D1.0mm

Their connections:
/Voltage and Current Measurements/ACS_VREF: ACSVref2.1 (1_1); also elsewhere on the board
/Voltage and Current Measurements/cur_sig: CurSig2.1 (1_1); also elsewhere on the board

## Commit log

2026-03-29 Initial commit.
    [KiCad Version: 9.0.8]
    [motor_testbench_v1_0.kicad_pcb, motor_testbench_v1_0.kicad_sch, power_regulation.kicad_sch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]
2026-04-01 Improved layout, added TVS diodes. Rotated ESP32, Changed proper SPI pins, finalized the load cell module area.
    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
    [motor_testbench_v1_0.kicad_pcb, motor_testbench_v1_0.kicad_sch, power_regulation.kicad_sch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]
2026-04-01 Moved the 1V8 Ref to bottom side of the board. Improved layout slightly / moved the Vref IC further away from hot / noisy side / further away from the noisy DCDC. Also managed to route the 1V8 and SP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
    [motor_testbench_v1_0.kicad_pcb, power_regulation.kicad_sch]
2026-04-03 Shortened high current path / improved the high current side layout.
    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
    [motor_testbench_v1_0.kicad_pcb]
2026-04-09 Improved layout.
    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
    [motor_testbench_v1_0.kicad_pcb, motor_testbench_v1_0.kicad_sch, power_regulation.kicad_sch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]
2026-04-09 Minor tweaks.
    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
    [motor_testbench_v1_0.kicad_pcb]
2026-06-18 Add proper Load Cell ADC. Improve everything. Almost ready.
    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
    [load_cell_measurement.kicad_sch, motor_testbench_v1_0.kicad_pcb, motor_testbench_v1_0.kicad_sch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]
2026-06-26 Switched isolating opamp. Switched Isolating DCDC converter. Minor layout improvements. Added load cell ADC.
    [KiCad Version: 10.0.4]
    [load_cell_measurement.kicad_sch, motor_testbench_v1_0.kicad_pcb, motor_testbench_v1_0.kicad_sch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]
2026-06-27 Implemented proper sallen key filter. Add 4V2 LDO Back.
    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
    [load_cell_measurement.kicad_sch, motor_testbench_v1_0.kicad_pcb, motor_testbench_v1_0.kicad_sch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]
2026-06-27 add buttons. Minor tweaks.
    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
    [load_cell_measurement.kicad_sch, motor_testbench_v1_0.kicad_pcb, motor_testbench_v1_0.kicad_sch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]
2026-06-28 Quite final version with ACS current sensor.
    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
    [motor_testbench_v1_0.kicad_pcb, power_regulation.kicad_sch, voltage_and_current_measurement.kicad_sch]
2026-06-28 Start adding new current sensor
    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
    [motor_testbench_v1_0.kicad_pcb, voltage_and_current_measurement.kicad_sch]
2026-07-03 Commit before 5V rebase.
    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
    [load_cell_measurement.kicad_sch, motor_testbench_v1_0.kicad_pcb, motor_testbench_v1_0.kicad_sch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]
2026-07-04 Implemented SAR ADC Buffering on top layer with one OPA387
    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
    [load_cell_measurement.kicad_sch, motor_testbench_v1_0.kicad_pcb, motor_testbench_v1_0.kicad_sch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]
2026-07-05 Implemented dual SAR ADC Buffering and Current sensor ratiometric supply
    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
    [load_cell_measurement.kicad_sch, motor_testbench_v1_0.kicad_pcb, power_regulation.kicad_sch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]
2026-07-05 Improved NTC measurements, improved layout. Added proper startup sequence for the power stages.
    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
    [load_cell_measurement.kicad_sch, motor_testbench_v1_0.kicad_pcb, power_regulation.kicad_sch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]
2026-07-05 Minor fixes.
    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
    [motor_testbench_v1_0.kicad_pcb]
2026-07-05 Add Shutdown Protection Diodes between Power Stages
    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
    [motor_testbench_v1_0.kicad_pcb, motor_testbench_v1_0.kicad_sch, power_regulation.kicad_sch]
2026-07-05 Minor tweaks.
    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
    [motor_testbench_v1_0.kicad_pcb]
2026-07-05 Add Kelvin voltage measurement.
    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
    [load_cell_measurement.kicad_sch, motor_testbench_v1_0.kicad_pcb, power_regulation.kicad_sch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]
2026-07-07 Add Secondary battery voltage measurement. Minor tweaks.
    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
    [load_cell_measurement.kicad_sch, motor_testbench_v1_0.kicad_pcb, motor_testbench_v1_0.kicad_sch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]
2026-07-07 Add full ESP32 DevKit Length PCB.
    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
    [motor_testbench_v1_0.kicad_pcb, motor_testbench_v1_0.kicad_sch, power_regulation.kicad_sch]
2026-07-08 Initial switch to ESP32 Module
    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
    [load_cell_measurement.kicad_sch, motor_testbench_v1_0.kicad_pcb, motor_testbench_v1_0.kicad_sch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]
2026-07-08 Commit before complete rework for ESP32S3Module
    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
    [motor_testbench_v1_0-B_Cu.gbr, motor_testbench_v1_0-B_Mask.gbr, motor_testbench_v1_0-B_Paste.gbr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]
2026-07-09 Started implementing ESP32Module
    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
    [load_cell_measurement.kicad_sch, motor_testbench_v1_0.kicad_pcb, motor_testbench_v1_0.kicad_sch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]
2026-07-09 Add few todo's
    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
    [power_regulation.kicad_sch]
2026-07-14 Continue implementing ESP32 module
    [KiCad Version: 10.0.3]
    [load_cell_measurement.kicad_sch, motor_testbench_v1_0.kicad_pcb, motor_testbench_v1_0.kicad_sch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]
2026-07-14 Add new GPIO header. Minor improvements.
    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
    [motor_testbench_v1_0.kicad_pcb, motor_testbench_v1_0.kicad_sch, power_regulation.kicad_sch]
2026-07-16 Add buffer OPA for Secondary battery measurement
    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
    [load_cell_measurement.kicad_sch, motor_testbench_v1_0.kicad_pcb, motor_testbench_v1_0.kicad_sch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]
2026-07-16 Add LDO / Power sequencing for sensors
    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
    [motor_testbench_v1_0.csv, motor_testbench_v1_0.kicad_pcb, motor_testbench_v1_0.kicad_sch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]
2026-07-19 Minor improvements
    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
    [motor_testbench_v1_0.kicad_pcb, power_regulation.kicad_sch]
2026-07-19 Minor improvements. Add 3D model.
    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
    [load_cell_measurement.kicad_sch, motor_testbench_v1_0.kicad_pcb, motor_testbench_v1_0.kicad_sch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]
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2026-07-19 Fix Via offset.
    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
    [load_cell_measurement.kicad_sch, motor_testbench_v1_0.kicad_sch, power_regulation.kicad_sch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]
2026-07-21 Minor improvements. Fix capacitor sizes.
    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
    [load_cell_measurement.kicad_sch, motor_testbench_v1_0.kicad_sch, power_regulation.kicad_sch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]
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2026-07-22 PCB improvements.
    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
    [load_cell_measurement.kicad_sch, motor_testbench_v1_0.kicad_sch, power_regulation.kicad_sch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]
2026-07-22 Add raytrace picture
    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
    [motor_testbench_v1_0_distributor_bom.csv, motor_testbench_v1_0_full_bom.csv]
2026-07-22 Fix bottom mask.
    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
2026-07-22 Add TPS7A20 LDO descriptions.
    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
    [motor_testbench_v1_0_full_bom.csv, power_regulation.kicad_sch]
